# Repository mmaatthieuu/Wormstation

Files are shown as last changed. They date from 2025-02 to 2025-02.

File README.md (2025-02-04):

# Wormstation

A fully open-source, all-in-one platform designed for **ease of use** and **accessibility**, yet offering **powerful, highly automated** solutions for laboratory-grade biological research. Wormstation is **ideal for high-throughput workflows** and **streamlined experimental processes**, particularly in _C. elegans_ studies and other small model organisms.

---

## Repositories

- **Wormstation Controller**  
  [GitHub: wormstation_controller](https://github.com/mmaatthieuu/wormstation_controller)  
  A user-friendly GUI that remotely controls the Wormstation Client software. It manages camera and LED settings, schedules recordings, and facilitates error checks or updates—all from a single interface.

- **Wormstation Client**  
  [GitHub: wormstation_client](https://github.com/mmaatthieuu/wormstation_client)  
  The client software running on each Wormstation device (e.g., Raspberry Pi). It handles local camera captures, LED strobing or continuous illumination, data compression, and robust logging routines.

---

## Hardware Overview

Below is an example Wormstation hardware setup, illustrating the 3D-printed housing, integrated cameras, LED arrays, and other key components:

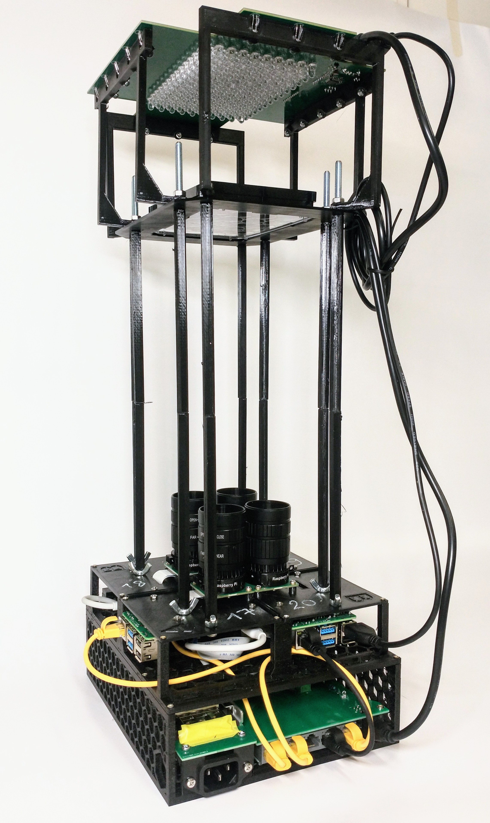
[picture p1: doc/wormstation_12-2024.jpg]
Wormstation Hardware


The complete mechanical and electronic designs (including 3D-printable files and KiCad schematics) are maintained in this repository, making the project fully open and reproducible.

---

## Key Features

- **High-Throughput**  
  Record multiple worms in parallel with automated capture schedules and minimal user intervention.
- **Fully Open-Source**  
  All code, hardware designs, and documentation are freely available for community-driven improvements.
- **Modular & Extensible**  
  Easily replace or upgrade components, adapt the software for new experimental protocols, or integrate additional sensors/actuators.
- **Optogenetics & Advanced Illumination**  
  Precisely control IR, blue, and orange LEDs for non-disruptive observation or targeted neural stimulation.
- **Comprehensive Logging**  
  Both the controller and the client track system status, events, and errors, aiding reproducibility and troubleshooting.

---

## Getting Started

1. **Hardware Assembly**  
   - Print the parts (`3D_print/` directory) and assemble according to the provided instructions.
   - Populate the PCB using KiCad files and a bill of materials found in the `electronics/` directory.
   - Mount the cameras, LED rings, or other illumination modules as described in the hardware guides.

2. **Software Installation**  
   - Set up the [Wormstation Client](https://github.com/mmaatthieuu/wormstation_client) on each device (e.g., Raspberry Pi).
   - Use the [Wormstation Controller](https://github.com/mmaatthieuu/wormstation_controller) GUI on your PC for centralized management.

3. **Configuration**  
   - Provide network addresses or hostnames in a `hosts.txt` file so the controller can detect each Wormstation on the LAN or VPN.
   - Customize recording schedules, LED parameters, and log verbosity per your research needs.

4. **Run Experiments**  
   - Start the controller application, select the devices, and define the experimental parameters.
   - Monitor live frames or single-shot previews to check focus/illumination.
   - Retrieve data automatically from each device or store on a NAS for uninterrupted long-term runs.

---

## Contributing

We welcome feedback, bug reports, and pull requests from the community. Please see the individual repositories for guidelines or open a GitHub Issue if you encounter any problems.

---

## License

This project is made available under the [MIT License](LICENSE). We encourage the community to adapt and expand Wormstation for diverse research applications.

---

## Contact

For questions, collaborations, or to share results:

- **Primary Maintainer**: [@mmaatthieuu](https://github.com/mmaatthieuu)  
- **Email**: [\<insert email\>](mailto:someone@example.com)

We look forward to hearing how Wormstation can accelerate your research!

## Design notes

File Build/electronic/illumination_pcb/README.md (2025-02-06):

# PCB_FT232H

Inspired from https://github.com/MaLoSW/PCB_FT232H

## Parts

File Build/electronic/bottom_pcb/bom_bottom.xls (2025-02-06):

Comment | Designator | Footprint |  | JLCPCB Part #
2 | J9 | PinHeader_1x02_P2.54mm_Vertical | Conn_01x02_Socket | C400349
3 | J8,J7,J6,J3,J2 | TerminalBlock_Phoenix_MKDS-1,5-2-5.08_1x02_P5.08mm_Horizontal | Rpi | C5183929
5 | J4 | DSUB-9_Female_Horizontal_P2.77x2.84mm_EdgePinOffset4.94mm_Housed_MountingHolesOffset7.48mm | DE9_Receptacle_MountingHoles | C3135162

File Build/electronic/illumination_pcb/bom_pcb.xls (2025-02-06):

Comment | Designator | Footprint | JLCPCB Part #
 | C1 | Capacitor_THT:CP_Radial_D10.0mm_P5.00mm | C2891075
D_sub15 | J1 | DSUB-9_Male_Horizontal_P2.77x2.84mm_EdgePinOffset4.94mm_Housed_MountingHolesOffset7.48mm | C591957
 | R1 | R_Axial_DIN0918_L18.0mm_D9.0mm_P22.86mm_Horizontal | C70856
 | J3,J4 | Connector_PinHeader_2.54mm:PinHeader_1x02_P2.54mm_Vertical | C400349
R1_other |  |  | C1364346
 |  |  |  | 1.7515
 |  |  |  | 3.3515

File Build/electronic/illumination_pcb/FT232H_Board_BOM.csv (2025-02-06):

Id | Designator | Footprint | Quantity | Designation | Supplier and ref
1 | H8,H7,H6,H5,H4,H3,H2,H1 | MountingHole_2.2mm_M2_Pad_Via | 8 | MountingHole
2 | C1,C2,C12,C6,C8,C13,C14,C16,C15,C10,C18 | C_0603_1608Metric_Pad1.08x0.95mm_HandSolder | 11 | 0.1uF
3 | C3,C4 | C_0603_1608Metric_Pad1.08x0.95mm_HandSolder | 2 | 27pF
4 | C17 | C_0603_1608Metric_Pad1.08x0.95mm_HandSolder | 1 | 10nF
5 | J3 | PinHeader_1x10_P2.54mm_Vertical | 1 | Conn_01x10
6 | L2,L3,L1 | L_0603_1608Metric_Pad1.05x0.95mm_HandSolder | 3 | 600R@0.5A
7 | R2,R21,R19 | R_0805_2012Metric_Pad1.20x1.40mm_HandSolder | 3 | 10k
8 | R5 | R_0805_2012Metric_Pad1.20x1.40mm_HandSolder | 1 | 12K@1%
9 | R6 | R_0805_2012Metric_Pad1.20x1.40mm_HandSolder | 1 | 2k
10 | U2 | SOT-23-6_Handsoldering | 1 | 93LCxxBxxOT
11 | R3,R4,R1,R23 | R_0805_2012Metric_Pad1.20x1.40mm_HandSolder | 4 | 0R
12 | PWR1,D5 | LED_0805_2012Metric_Pad1.15x1.40mm_HandSolder | 2 | RED
13 | R7,R18 | R_0805_2012Metric_Pad1.20x1.40mm_HandSolder | 2 | 600R
14 | J2 | PinHeader_1x08_P2.54mm_Vertical | 1 | Conn_01x08
15 | R8,R9,R10 | R_0805_2012Metric_Pad1.20x1.40mm_HandSolder | 3 | 10K
16 | Y1 | Crystal_SMD_5032-2Pin_5.0x3.2mm_HandSoldering | 1 | 12MHz@12ppm
17 | F1 | Fuse_0805_2012Metric_Pad1.15x1.40mm_HandSolder | 1 | 0ZCK0010FF2G
18 | J1 | USB_B_OST_USB-B1HSxx_Horizontal | 1 | USB_B
19 | C11,C7 | CP_EIA-1608-10_AVX-L_Pad1.25x1.05mm_HandSolder | 2 | 4.7uF
20 | J4 | PinHeader_2x02_P2.54mm_Vertical | 1 | POWER
21 | R12,R14,R13 | R_0805_2012Metric_Pad1.20x1.40mm_HandSolder | 3 | 1.3k
22 | C24,C23,C22 | C_0603_1608Metric_Pad1.08x0.95mm_HandSolder | 3 | 1nF
23 | D3,D2,D4,D6 | LED_0603_1608Metric_Pad1.05x0.95mm_HandSolder | 4 | GREEN
24 | R22 | R_0805_2012Metric_Pad1.20x1.40mm_HandSolder | 1 | 100
25 | U4,U5,U3 | QFN-40-1EP_5x5mm_P0.4mm_EP3.6x3.6mm_ThermalVias | 3 | LP5860T
26 | R11,R16,R15 | R_0805_2012Metric_Pad1.20x1.40mm_HandSolder | 3 | 4.7kR
27 | C26,C28,C31,C32,C21,C33,C27,C20,C19 | C_0603_1608Metric_Pad1.08x0.95mm_HandSolder | 9 | 1uF
28 | J5 | Molex_Micro-Fit_3.0_43045-0421_2x02-1MP_P3.00mm_Horizontal | 1 | Molex Micro-Fit
29 | R17,R20 | R_0805_2012Metric_Pad1.20x1.40mm_HandSolder | 2 | 480R
30 | D1 | LED_0603_1608Metric_Pad1.05x0.95mm_HandSolder | 1 | YELLOW
31 | D7 | LED_1206_3216Metric_Pad1.42x1.75mm_HandSolder | 1 | BLUE
32 | SW1 | SW_Push_2P2T_Toggle_CK_PVA2xxH3xxxxxxV2 | 1 | RESET
33 | C30 | CP_Radial_D10.0mm_P5.00mm | 1 | 1000uF
34 | C5,C9 | CP_EIA-1608-08_AVX-J_Pad1.25x1.05mm_HandSolder | 2 | 4.7uF
35 | U1 | LQFP-48_7x7mm_P0.5mm | 1 | FT232H
36 | TVS2,TVS1 | D_0603_1608Metric_Pad1.05x0.95mm_HandSolder | 2 | PGB1010603
37 | DO53,DO87,DO104,DO86,DO3,DO18,DO47,DO60,DO32,DO70,DO56,DO83,DO35,DO111,DO82,DO19,DO69,DO25,DO17,DO105,DO94,DO67,DO103,DO8,DO88,DO54,DO36,DO2,DO1,DO50,DO95,DO49,DO6,DO110,DO55,DO52,DO89,DO37,DO77,DO115,DO63,DO15,DO68,DO45,DO109,DO9,DO75,DO41,DO34,DO26,DO99,DO116,DO80,DO65,DO10,DO72,DO23,DO16,DO31,DO112,DO4,DO73,DO108,DO43,DO81,DO85,DO44,DO117,DO13,DO7,DO14,DO79,DO38,DO74,DO61,DO92,DO28,DO40,DO66,DO5,DO71,DO51,DO96,DO39,DO22,DO62,DO76,DO11,DO46,DO107,DO100,DO91,DO90,DO27,DO24,DO98,DO21,DO93,DO113,DO48,DO29,DO97,DO33,DO57,DO59,DO106,DO101,DO20,DO78,DO114,DO84,DO64,DO42,DO102,DO58,DO12,DO30 | LED_D5.0mm | 117 | LED_Opto_590
38 | DB103,DB14,DB92,DB133,DB38,DB41,DB62,DB25,DB125,DB70,DB108,DB137,DB83,DB23,DB60,DB1,DB121,DB10,DB24,DB6,DB78,DB99,DB2,DB31,DB16,DB89,DB20,DB66,DB77,DB76,DB132,DB127,DB105,DB13,DB46,DB93,DB85,DB64,DB27,DB128,DB57,DB17,DB67,DB40,DB12,DB110,DB140,DB86,DB54,DB9,DB129,DB95,DB75,DB130,DB113,DB104,DB48,DB19,DB126,DB69,DB61,DB109,DB15,DB7,DB11,DB18,DB65,DB74,DB51,DB34,DB114,DB101,DB73,DB134,DB120,DB47,DB63,DB80,DB36,DB115,DB72,DB4,DB52,DB111,DB82,DB58,DB44,DB136,DB139,DB33,DB123,DB100,DB22,DB131,DB119,DB53,DB3,DB5,DB91,DB90,DB97,DB122,DB117,DB79,DB43,DB107,DB49,DB37,DB84,DB68,DB32,DB118,DB98,DB116,DB87,DB106,DB42,DB8,DB30,DB94,DB28,DB35,DB56,DB39,DB138,DB96,DB112,DB26,DB71,DB59,DB102,DB81,DB29,DB88,DB21,DB50,DB124,DB55,DB45,DB135 | LED_D5.0mm | 140 | LED_Blue_470
39 | DIR16,DIR7,DIR1,DIR4,DIR5,DIR11,DIR13,DIR12,DIR10,DIR14,DIR9,DIR8,DIR3,DIR6,DIR15,DIR2 | LED_D5.0mm | 16 | LED_IR_850
40 | Q1,Q2 | SOT-23 | 2 | NPN
41 | C25 | CP_EIA-1608-10_AVX-L_Pad1.25x1.05mm_HandSolder | 1 | 10uF

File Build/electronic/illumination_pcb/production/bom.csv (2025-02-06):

Designator | Footprint | Quantity | Value | LCSC Part #
C1, C10, C12, C13, C14, C15, C16, C18, C2, C6, C8 | 0402 | 11 | 0.1uF | C2655418
C11, C5, C7, C9 | 0603 | 4 | 4.7uF | C5596636
C17 | 0603 | 1 | 10nF | C43253
C19, C20, C21, C26, C27, C28, C31, C32, C33 | 0603 | 9 | 1uF | C76619
C22, C23, C24 | 0402 | 3 | 1nF | C147546
C25 | 1210 | 1 | 10uF | C597571
C3, C4 | 0402 | 2 | 16pF | C513591
C30 | CP_Radial_D8.0mm_P3.50mm | 1 | 1000uF | C840077
D1, D2, D3 | 0603 | 3 | YELLOW | C189306
D4, D6 | 0603 | 2 | GREEN | C7496818
D5, PWR1 | 0805 | 2 | RED | C7496834
D7 | 1206 | 1 | BLUE | C965858
DB1, DB10, DB100, DB101, DB102, DB103, DB104, DB105, DB106, DB107, DB108, DB109, DB11, DB110, DB111, DB112, DB113, DB114, DB115, DB116, DB117, DB118, DB119, DB12, DB120, DB121, DB122, DB123, DB124, DB125, DB126, DB127, DB128, DB129, DB13, DB130, DB131, DB132, DB133, DB134, DB135, DB136, DB137, DB138, DB139, DB14, DB140, DB15, DB16, DB17, DB18, DB19, DB2, DB20, DB21, DB22, DB23, DB24, DB25, DB26, DB27, DB28, DB29, DB3, DB30, DB31, DB32, DB33, DB34, DB35, DB36, DB37, DB38, DB39, DB4, DB40, DB41, DB42, DB43, DB44, DB45, DB46, DB47, DB48, DB49, DB5, DB50, DB51, DB52, DB53, DB54, DB55, DB56, DB57, DB58, DB59, DB6, DB60, DB61, DB62, DB63, DB64, DB65, DB66, DB67, DB68, DB69, DB7, DB70, DB71, DB72, DB73, DB74, DB75, DB76, DB77, DB78, DB79, DB8, DB80, DB81, DB82, DB83, DB84, DB85, DB86, DB87, DB88, DB89, DB9, DB90, DB91, DB92, DB93, DB94, DB95, DB96, DB97, DB98, DB99 | LED_D5.0mm | 140 | LED_Blue_470
DIR1, DIR10, DIR11, DIR12, DIR13, DIR14, DIR15, DIR16, DIR2, DIR3, DIR4, DIR5, DIR6, DIR7, DIR8, DIR9 | LED_D5.0mm | 16 | LED_IR_850
DO1, DO10, DO100, DO101, DO102, DO103, DO104, DO105, DO106, DO107, DO108, DO109, DO11, DO110, DO111, DO112, DO113, DO114, DO115, DO116, DO117, DO12, DO13, DO14, DO15, DO16, DO17, DO18, DO19, DO2, DO20, DO21, DO22, DO23, DO24, DO25, DO26, DO27, DO28, DO29, DO3, DO30, DO31, DO32, DO33, DO34, DO35, DO36, DO37, DO38, DO39, DO4, DO40, DO41, DO42, DO43, DO44, DO45, DO46, DO47, DO48, DO49, DO5, DO50, DO51, DO52, DO53, DO54, DO55, DO56, DO57, DO58, DO59, DO6, DO60, DO61, DO62, DO63, DO64, DO65, DO66, DO67, DO68, DO69, DO7, DO70, DO71, DO72, DO73, DO74, DO75, DO76, DO77, DO78, DO79, DO8, DO80, DO81, DO82, DO83, DO84, DO85, DO86, DO87, DO88, DO89, DO9, DO90, DO91, DO92, DO93, DO94, DO95, DO96, DO97, DO98, DO99 | LED_D5.0mm | 117 | LED_Opto_590
F1 | 0805 | 1 | 0ZCK0010FF2G | C516070
H1, H2, H3, H4, H5, H6, H7, H8 | MountingHole_2.2mm_M2_Pad_Via | 8 | MountingHole
J1 | USB_B_OST_USB-B1HSxx_Horizontal | 1 | USB_B | C464566
J2 | PinHeader_1x08_P2.54mm_Vertical | 1 | Conn_01x08 | C6332201
J3 | PinHeader_1x10_P2.54mm_Vertical | 1 | Conn_01x10 | C5383117
J4 | PinHeader_2x02_P2.54mm_Vertical | 1 | POWER | C5383103
J5 | Molex_Micro-Fit_3.0_43045-0400_2x02_P3.00mm_Horizontal | 1 | Molex Micro-Fit | C122413
L1, L2, L3 | L_Murata_LQH2MCNxxxx02_2.0x1.6mm | 3 | 600R@0.5A | C917337
Q1, Q2 | SOT-23 | 2 | NPN | C18221467
R1, R23, R3, R4 | 1206 | 4 | 0R | C2074152
R10, R19, R2, R21, R8, R9 | 0805 | 6 | 10k | C163957
R11, R15, R16 | 0805 | 3 | 4.7kR | C192064
R12, R13, R14 | 0603 | 3 | 1.3k | C334843
R17, R20 | 0805 | 2 | 480R | C144560
R18, R7 | 0805 | 2 | 600R | C706363
R22 | 0603 | 1 | 100 | C844726
R5 | 0805 | 1 | 12K@1% | C515719
R6 | 0805 | 1 | 2k | C2934151
SW1 | SW_Push_2P2T_Toggle_CK_PVA2xxH3xxxxxxV2 | 1 | RESET | C528785
TVS1, TVS2 | 0603 | 2 | PGB1010603 | C10677
U1 | LQFP-48_7x7mm_P0.5mm | 1 | FT232H | C51997
U2 | SOT-23-6_Handsoldering | 1 | 93LCxxBxxOT | C190271
U3, U4, U5 | QFN-40-1EP_5x5mm_P0.4mm_EP3.6x3.6mm | 3 | LP5860T | C22427238
Y1 | Crystal_SMD_3225-4Pin_3.2x2.5mm_HandSoldering | 1 | 12MHz@12ppm | C668846

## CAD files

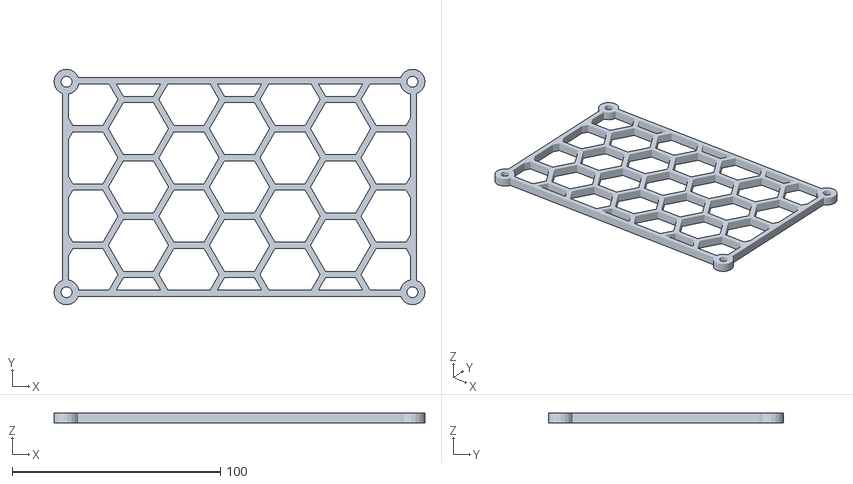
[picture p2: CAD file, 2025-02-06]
Build/3D_print/STL files/led_solder_holder.stl
178.0 x 113.0 x 5.00

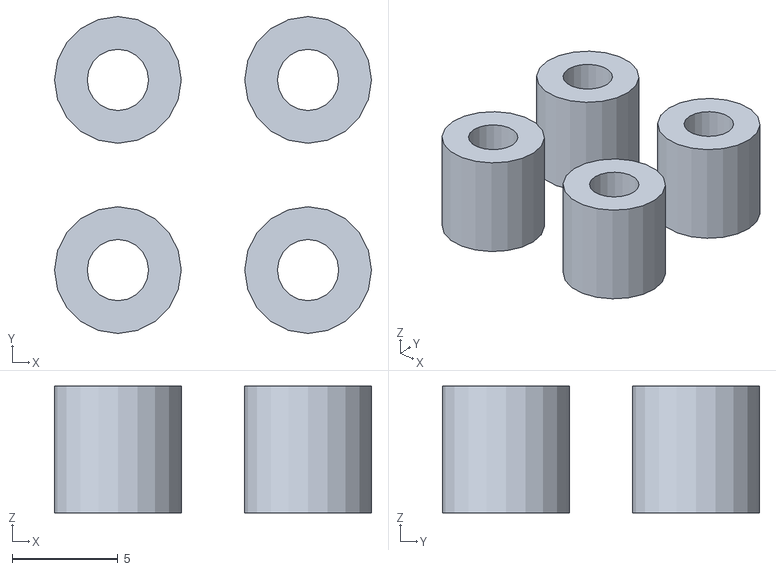
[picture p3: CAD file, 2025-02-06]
Build/3D_print/STL files/spacers.stl
15.0 x 15.0 x 6.00

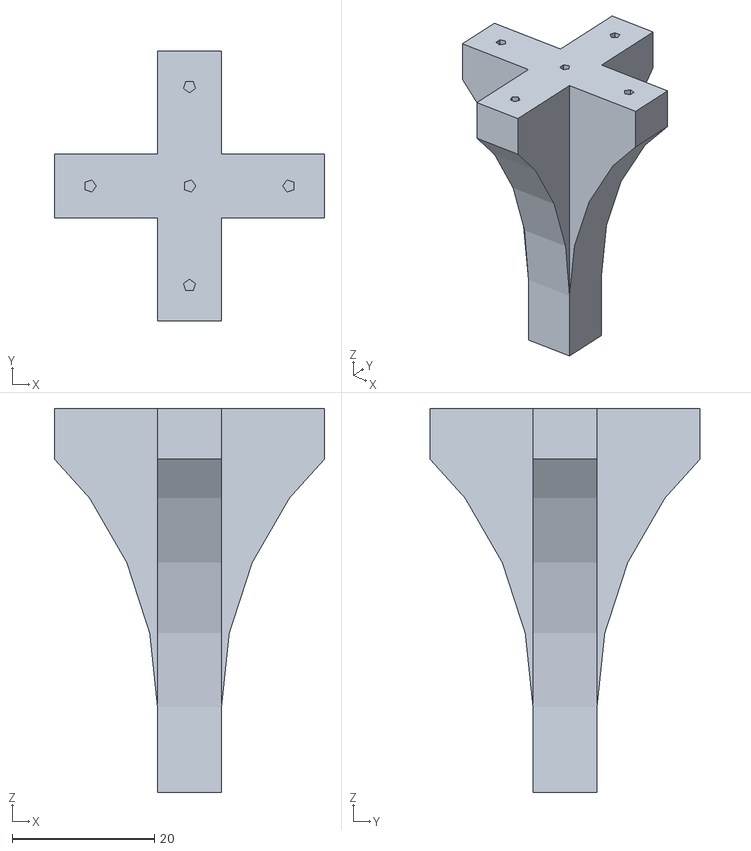
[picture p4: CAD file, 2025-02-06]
Build/3D_print/STL files/central_pillar.stl
38.0 x 38.0 x 54.0

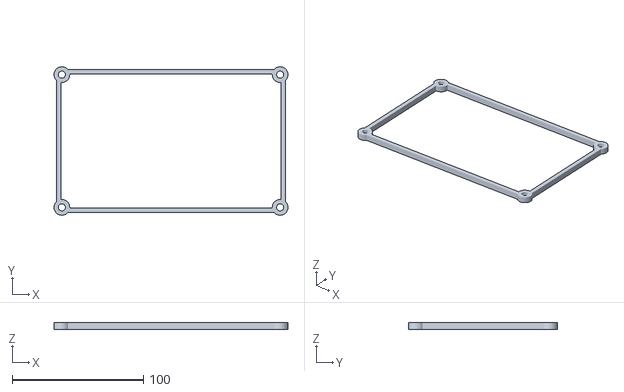
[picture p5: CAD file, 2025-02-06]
Build/3D_print/STL files/led_solder_mold_rect.stl
178.0 x 113.0 x 5.00

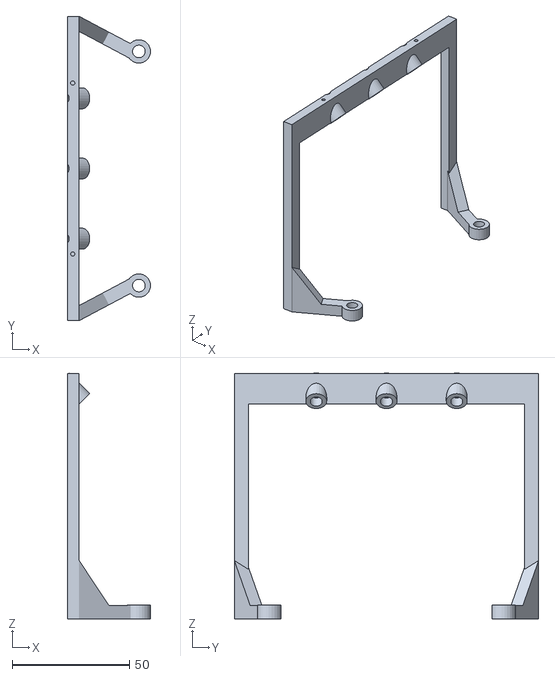
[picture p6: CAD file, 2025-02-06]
Build/3D_print/STL files/multi_led_3.stl
35.5 x 130.0 x 105.1

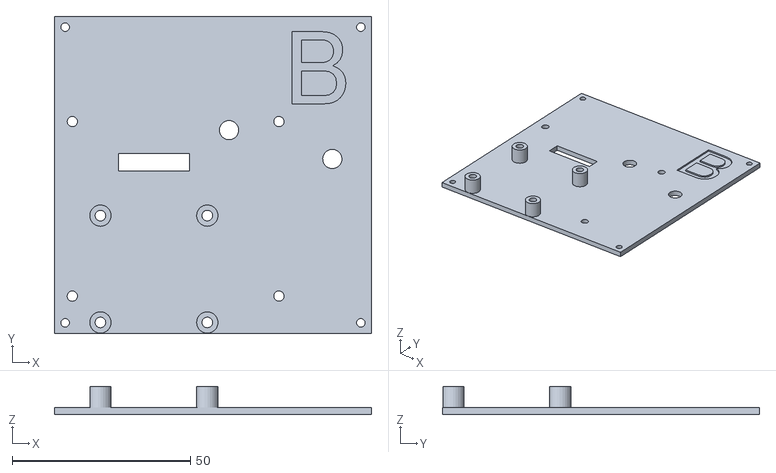
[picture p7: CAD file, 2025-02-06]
Build/3D_print/STL files/Camera_plate_B.stl
89.0 x 89.0 x 8.00

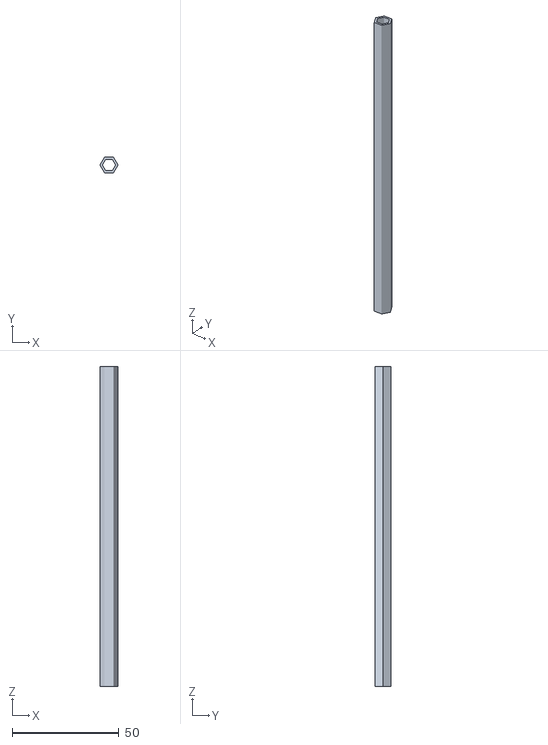
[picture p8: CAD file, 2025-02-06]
Build/3D_print/STL files/leg150.stl
8.50 x 7.36 x 150.0

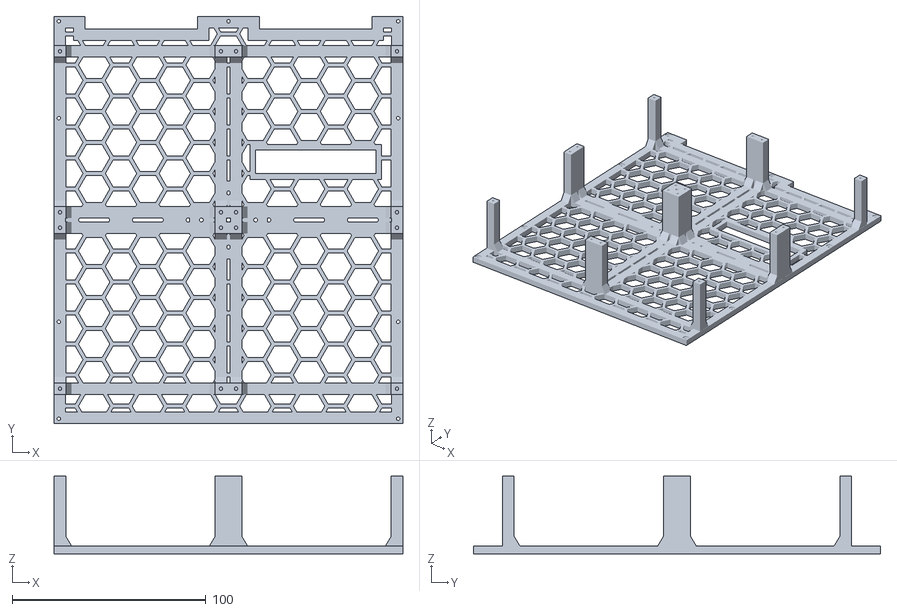
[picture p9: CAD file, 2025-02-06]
Build/3D_print/STL files/middle.stl
180.0 x 210.0 x 40.0

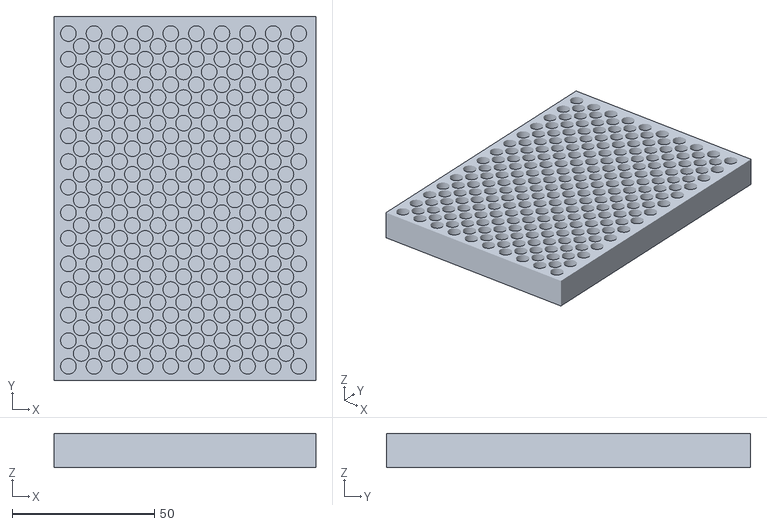
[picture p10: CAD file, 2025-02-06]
Build/3D_print/STL files/led_solder_mold.stl
92.0 x 128.0 x 12.0

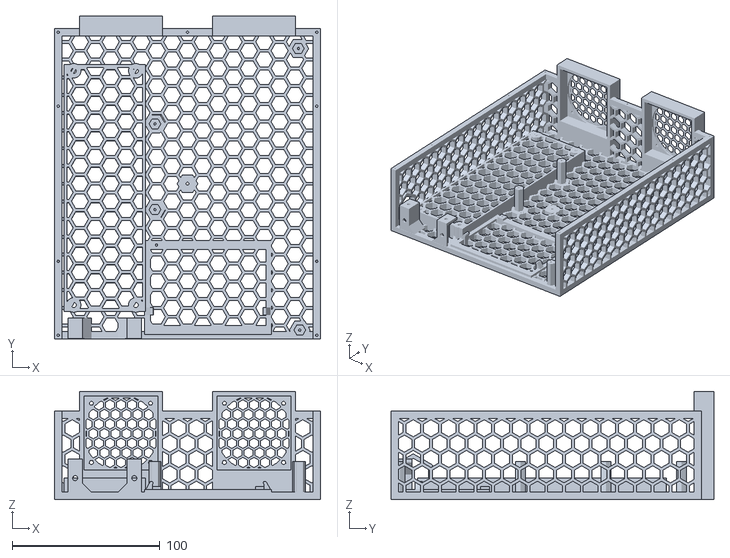
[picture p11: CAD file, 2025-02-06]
Build/3D_print/STL files/bottom.stl
180.0 x 218.6 x 73.2

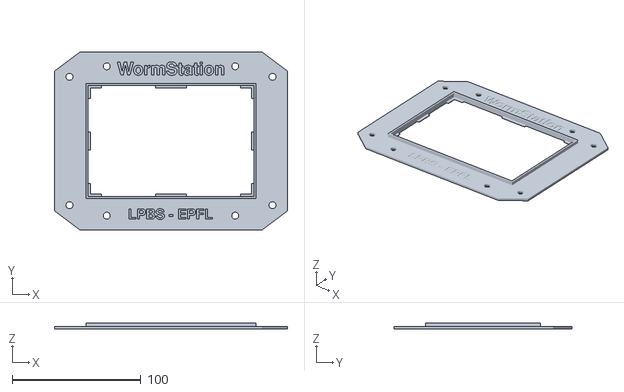
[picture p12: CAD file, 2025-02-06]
Build/3D_print/STL files/microwell_holder.stl
181.1 x 138.6 x 5.00

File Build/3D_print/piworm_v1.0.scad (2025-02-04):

/*
 * Wormstation
 * by Matthieu Schmidt - https://github.com/mmaatthieuu/Wormstation
 * created 2021-03-15
 * updated 2025-01-09
 * version v1.0
 *
 * Changelog
 * --------------
 * v1.0:
 *      - Massive clean
 *      - Improved customizer
 * v0.6.2:
 *      - New basement floor for new PCB
 *      - New basement
 *      - Remove side wall on cam plate
 *      - Remove old modules
 *      - Multi_LED_bar_v3 (more space between legs for N=3)
 * v0.6.1:
 *      - remove unused modules
 *      - wheels, breadboard, windshield
 * v0.6:
 *      - add screw holes in Led bars
 *      - add PCB cover
 *      - one single big foot
 *      - add chemotaxis mode
 *      - remove unused parts in the code
 * --------------
 *
 * This work is licensed under the MIT License.
 */


 // Parameter Section //
//-------------------//

/* [Global display settings] */


// Enable Draft Mode to ignore shape details and speed up rendering. It also shows non-pritable parts as lenses or perti dishes.
DRAFT_MODE = true;


// Choose between a setup for microwell plates or 5cm petri plates
SETUP_VERSION = "Microwell"; // [Microwell, Petri]

// Render all parts
SHOW_ALL = false;

// Show light emitted by the LEDs
Show_light_rays = false;

/* [Main parts display settings] */

Multi_LED_bar = false;
Multi_LED_bar_size= 5; // [3,4,5]

Multiwell_holder = false;
Large_plate_holder = false;
Leg=false;


Camera_plate_A = false;
Camera_plate_B = false;

Central_pillar=false;
Basement=false;
Basement_floor=false;



/* [Secondary parts display settings] */

Petri_adapter = false;
Spacers = false;

Filter_adapter=false;
Filter_adapter_HQ_long=false;
Filter_adapter_HQ_short=false;

Led_solder_mold=false;







/* [Custom Settings] */





//____________ VARIABLES ______________

tolerance = 0.2;

width = 2;
width_cam_plate = 2; //same as width

leg_space = 50.0;


LED_insert_width = 9;


LED_angle = 137;
LED_height = 250;
LED_shift = 90;
LED_viewing_angle = 20;



petri_filler_thickness = 12;

Leg_length=150; // [80:220]


middle_floor_thickness = 4;

pillar_position_1 = [-30,3.65,0];
//pillar_position_2 = 


 // Import Section //
//-------------------//


module mount(){
    
    import("lib/lens_mount.stl");
    
}
// EXTERNAL FILES

use <lib/threads.scad> 
use <lib/basic_shapes.scad>
use <lib/hex-grid.scad>




//____________ PHYSICAL PARAMETERS ______________


large_d = 88.1+tolerance;   // Main petri dish
small_d = 36+tolerance;   // Small petri dishes

large_d_in = 86.8-tolerance;  // Inside diameter main petri dish

external_size = 89;
o = external_size*0.5*0.8;


camera_hole = 9.2+tolerance; // 8mm square
camera_x = 30.0;
camera_screw_centre_offset = 0.0;
camera_screw_x = 12.5;
camera_screw_y = 21.0; // 21mm screw spacing
camera_screw_r = 1.5; // m2
camera_cable_y = 20.0;
camera_cable_h = 1.0;



//____________ GLOBAL VALUES ______________


R_ext = large_d/2;
r = small_d/2+0.1;

R_in = large_d_in/2;


imbrications_size = 1;

space_between_plates = 1.8;

//wall = 2;


sep = 10;

feet_height=40;
feet_width = 6;
feet_center_pos = external_size/2-feet_width/2;

fcp = feet_center_pos;





L=R_in-r;
alpha=(asin(r/L)-45)*2;



//////////////////////////////////////////

if(SHOW_ALL){
    DRAFT_MODE = true;
    show_all();
}
module show_all(){
    

   
  if(SETUP_VERSION == "Petri"){
      translate([0,0,135])large_plate_holder_v2();
      
    translate([0,31.5,0])multi_LED_bar_v3(4);
    mirror([0,1,0])translate([0,31.5,0])multi_LED_bar_v3(4);
    translate([-31.5,0,0])rotate([0,0,90])multi_LED_bar_v3(4);
      
      
  }
  else{
      translate([0,0,135])multiwell_holder();
      
      translate([0,31.5,0])multi_LED_bar_v3(5);
      mirror([0,1,0])translate([0,31.5,0])multi_LED_bar_v3(5);
      translate([-31.5,0,0])rotate([0,0,90])multi_LED_bar_v3(3);
  }
    
  camera_plate();
  rotate([0,0,90]){
    translate([0,0,-90])basement_v2();
    translate([0,0,-110])basement_floor_v2();
  }

    

    
}





module LED_bar_foot(h, shift){
    translate([0,shift,h])mCube(6-tolerance/2,5,95);
    
    // Corners for robustness
    translate([-3,shift-16,h+5])prism(6,15,20);
    
    translate([0,shift-19+12,h])mCube(6,15,6-tolerance/2);
    
    difference(){
        union(){
            translate([0,shift-19-0,h])mCube(6-tolerance*1.5,20,6-tolerance*1.5);
            translate([0,shift-19-2*4-1,h])rotate([0,0,0])cylinder(h=6-tolerance/2,d=10);
        }
        translate([0,shift-19-2*4-1,h])rotate([0,0,0])cylinder(h=200,d=5.4);
    }
}

module LED_bar_foot_rotation(h, shift){

    leg_offset = 12;
    
    translate([leg_offset,shift,h])mCube(6-tolerance/2,5,95);
    
    // Corners for robustness
    translate([5.93,2.95,0])translate([-3,shift-16,h+5])rotate([0,0,-28])prism(5.7,15,20);
    
    //translate([0,shift-19+12,h])mCube(6,15,6-tolerance/2);
    
    difference(){
        union(){
            translate([5.443,shift-19+4.6,h])rotate([0,0,-28])mCube(6-tolerance*1.5,30,6-tolerance*1.5);
            translate([0,shift-19-2*4-1,h])rotate([0,0,0])cylinder(h=6-tolerance/2,d=10);
        }
        translate([0,shift-19-2*4-1,h])rotate([0,0,0])cylinder(h=200,d=5.4);
    }
    
}

module crop_LED_bar(L,width){
    difference(){
        mCube(L,width,13);
        for(m=[0,1]){
            mirror([m,0,0])translate([leg_space,-4,13])rotate([65,0,0])cube(10,10,10);
        }
    }
}

module multi_LED_bar_v3(N, rotate_feet=false){
    
    //bool_64 = -(N-4)*0.5; // 0 si N==6, 1 si N==4
    bool_64 = 0;
    
    //shift = 85+ bool_64*(127.2-85.1)/2;
    //echo(str(shift));
    shift = 74.5+1;
    //x_shift = -bool_64 * 1;
    x_shift = 0;
    width = 5;
    h=135+3+tolerance/2;
    y_space = leg_space;
    
    //angle_0 = 142 - (bool_64*4.5);
    angle_0 = 143;
    
    echo(N);
    echo(angle_0);
    
    pcb_holes_space = 123;
    
    $fn=25;
    
    difference(){
        union(){
            // Main bar
            if(N==5){
                translate([x_shift,shift,230])crop_LED_bar(130,width);
            }
            else{
                translate([x_shift,shift,230])mCube(130,width,13);
            }
            
            
            //LED tubes
            translate([x_shift,shift+5,240])rotate([0,-angle_0+8,90])LED_bar(N);
            
            
            for(m=[0,1]){
                if(N==3){
                    mirror([m,0,0])translate([y_space,-0,0])LED_bar_foot_rotation(h, shift);
                }
                else{
                    mirror([m,0,0])translate([y_space,-0,0])LED_bar_foot(h, shift);
                }
            }
           
            
        }
        
        union(){
        //translate([x_shift,shift,260])rotate([0,-angle_0,90])LED_bar_negative(N);
        translate([x_shift,shift+5,240])rotate([0,-angle_0+8,90])LED_bar_negative(N);
        //translate([x_shift,shift+5,220])rotate([0,-angle_0+13,90])LED_bar_negative(N);
        translate([x_shift,shift+width+width/2,210])mCube(300,width*2,55);
        
        // PCB screw hole
         if(N==3){
             pcb_holes_space = 73;   // if N==3
             translate([pcb_holes_space/2,-31.5+150.25-43,h+95-3])cylinder(h=13, d=1.85);
             mirror([1,0,0])translate([pcb_holes_space/2,-31.5+150.25-43,h+95-3])cylinder(h=13, d=1.8);
         }
         else{  // N==4 or 5
            pcb_holes_space = 123;
            translate([pcb_holes_space/2,-31.5+150.25-43,h+95-3])cylinder(h=13, d=1.85);
            mirror([1,0,0])translate([pcb_holes_space/2,-31.5+150.25-43,h+95-3])cylinder(h=13, d=1.8);
          }
        
        }
    
             
    }
    
    
}
if(Multi_LED_bar){
    translate([0,0,85])
    //for(i=[0,1]){
    for(i=[0]){
mirror([i,0,0])rotate([0,0,90])translate([0,31.5,-86])multi_LED_bar_v3(Multi_LED_bar_size);
    }
}
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

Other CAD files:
Build/3D_print/STL files/Camera_plate_A.stl
Build/3D_print/STL files/multi_led_5.stl

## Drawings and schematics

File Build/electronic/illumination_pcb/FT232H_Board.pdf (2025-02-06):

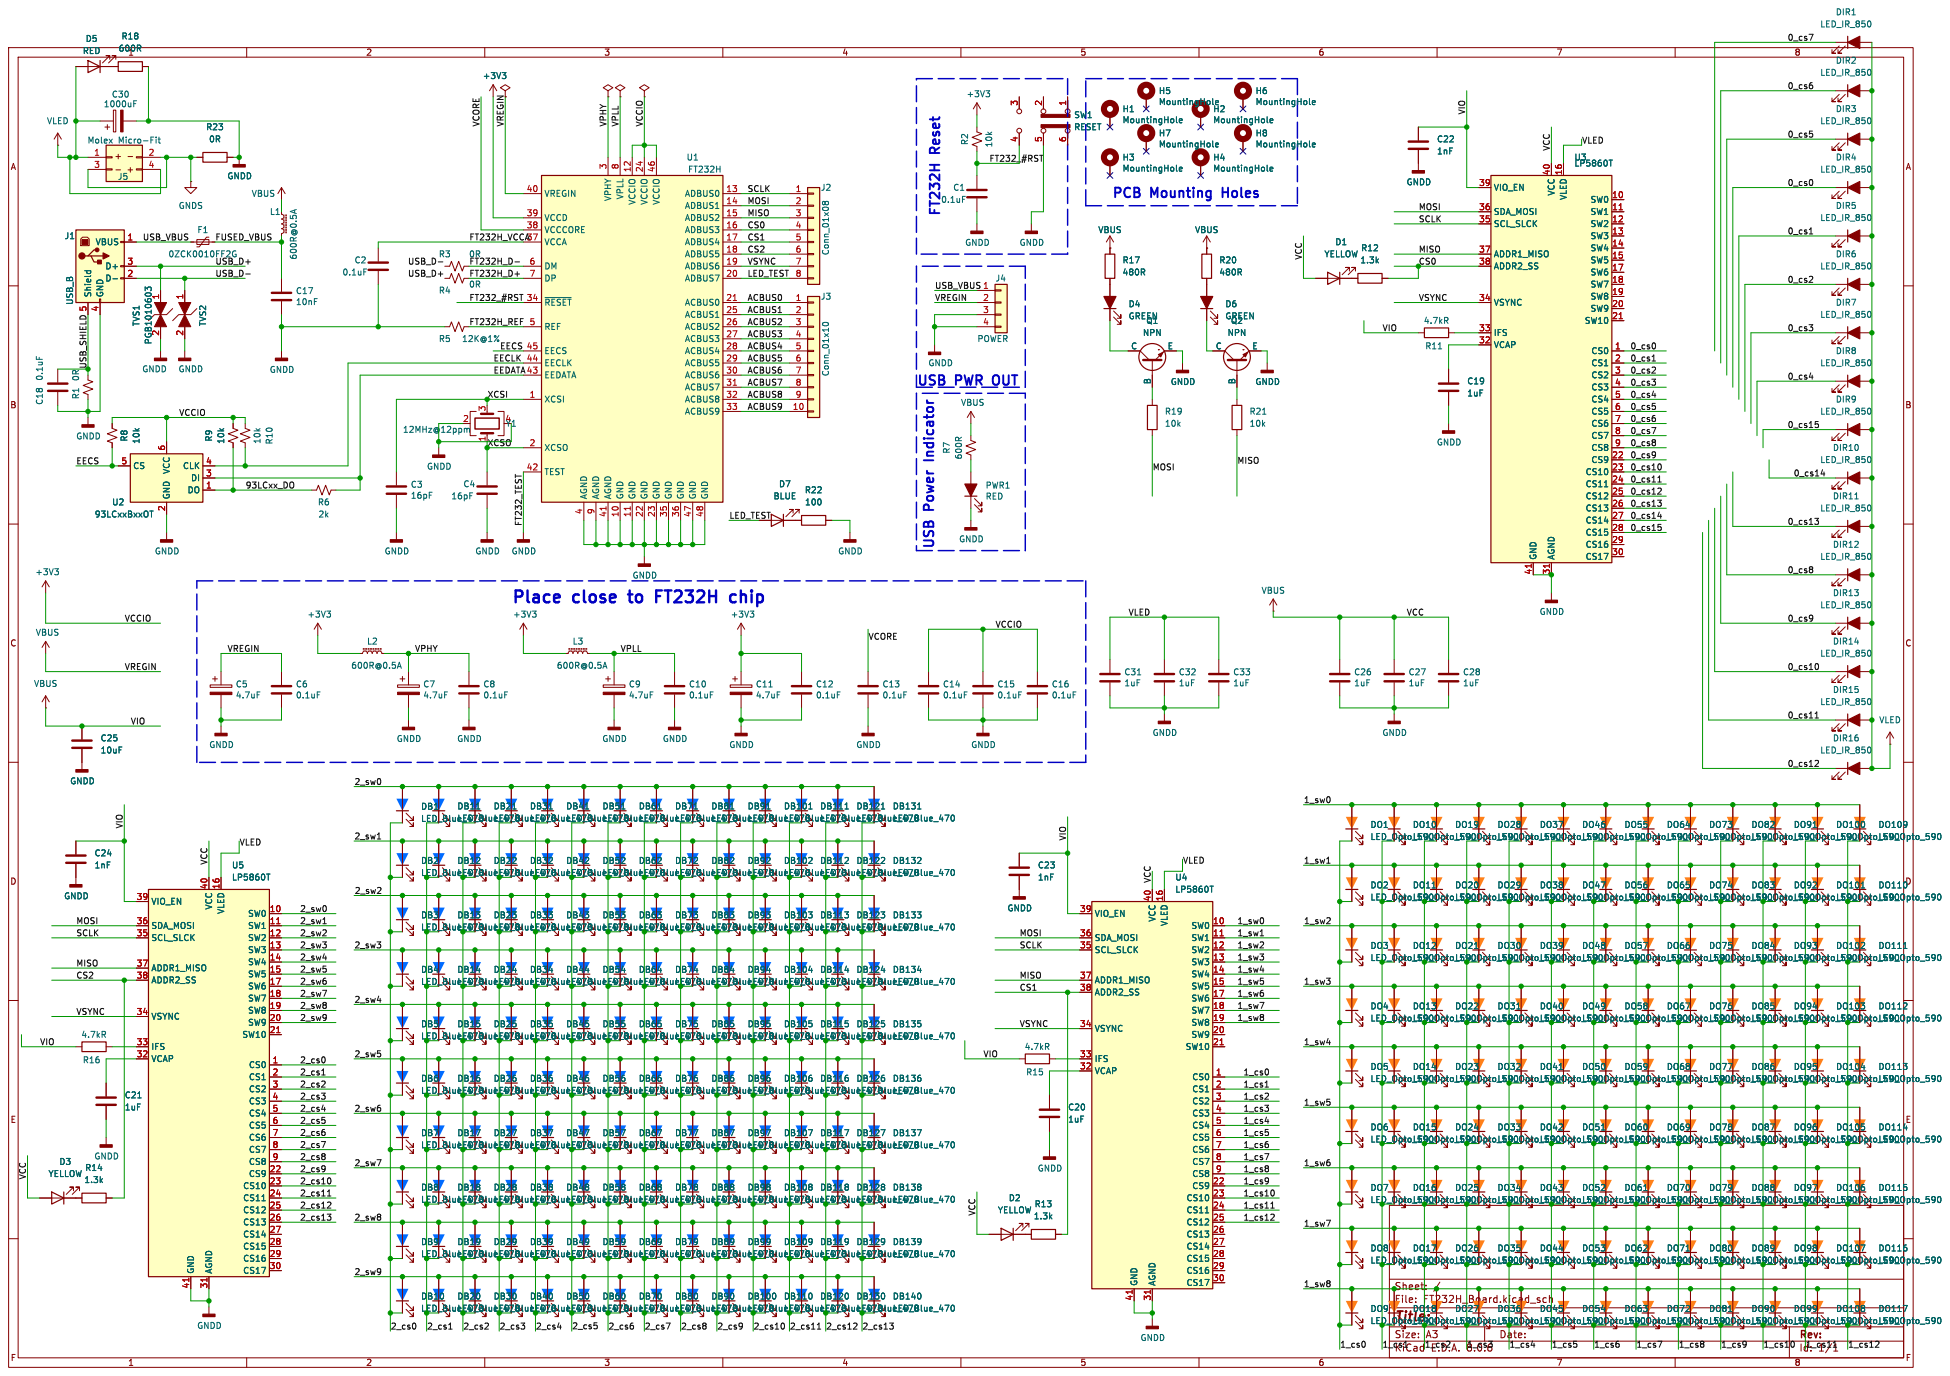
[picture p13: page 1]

MISO MOSI SCLK VPHY
SCLK VPLL

4 VREGIN 40 AGND 41 TEST 42 EEDATA 43 EECLK 44 EECS 45 VCCIO 46 GND 47 GND 48 REF 5 DM 6 DP 7 VPLL

3 ACBUS6 30 ACBUS7 31 ACBUS8 32 ACBUS9 33 ~{RESET} 34 GND 35 GND 36 VCCA 37 VCCCORE 38 VCCD 39 AGND

2 DI 3 CLK 4 CS 5 VCC

Place close to FT232H chip

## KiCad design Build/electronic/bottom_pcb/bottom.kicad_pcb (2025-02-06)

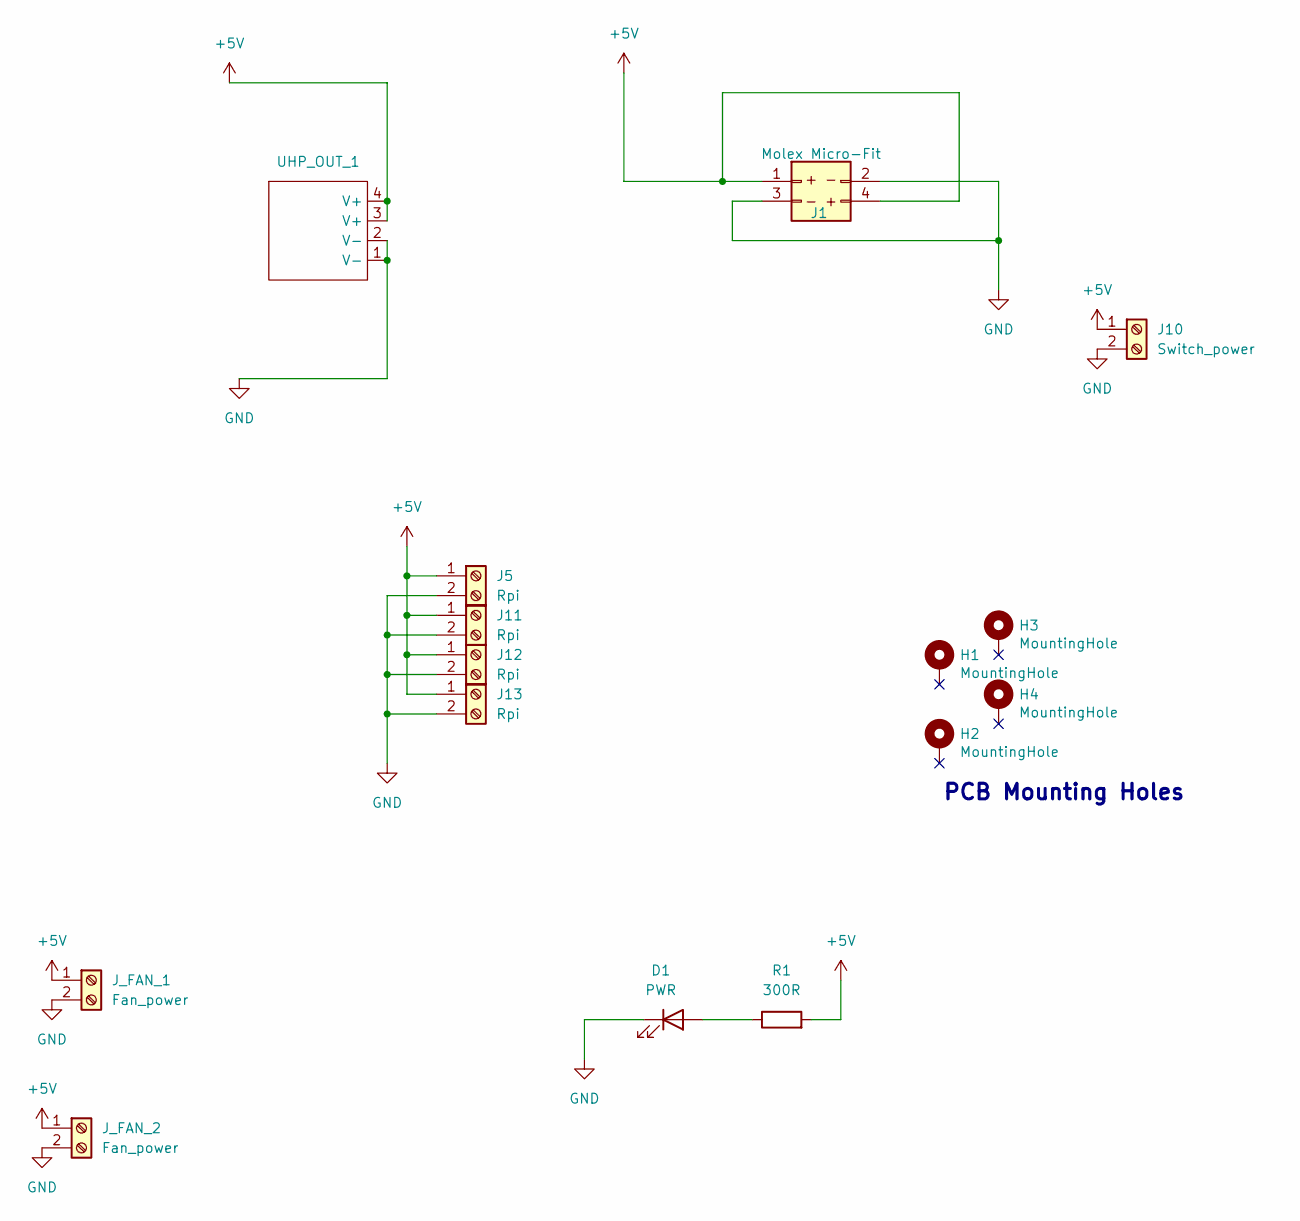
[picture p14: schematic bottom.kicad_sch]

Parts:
D1: PWR; LED_D3.0mm
H1, H2, H3, H4: MountingHole; MountingHole_2.2mm_M2_Pad_Via
J1: Molex Micro-Fit; Molex_Micro-Fit_3.0_43045-0400_2x02_P3.00mm_Horizontal; LCSC C122413
J5, J11, J12, J13: Rpi; TerminalBlock_Phoenix_MKDS-1,5-2-5.08_1x02_P5.08mm_Horizont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
J10: Switch_power; TerminalBlock_Phoenix_MKDS-1,5-2-5.08_1x02_P5.08mm_Horizont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
J_FAN_1, J_FAN_2: Fan_power; TerminalBlock_Phoenix_MKDS-1,5-2-5.08_1x02_P5.08mm_Horizont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
R1: 300R; R_Axial_DIN0207_L6.3mm_D2.5mm_P15.24mm_Horizontal
UHP_OUT_1: UHP-200A-5_output

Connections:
+5V: J1.1 (5V), J1.4, J5.1, J10.1, J11.1, J12.1, J13.1, J_FAN_1.1, J_FAN_2.1, R1.2, UHP_OUT_1.3 (V+), UHP_OUT_1.4 (V+)
GND: D1.1 (K), J1.2 (GND), J1.3 (GND), J5.2, J10.2, J11.2, J12.2, J13.2, J_FAN_1.2, J_FAN_2.2, UHP_OUT_1.1 (V-), UHP_OUT_1.2 (V-)
unnamed: D1.2 (A), R1.1

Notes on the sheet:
PCB Mounting Holes

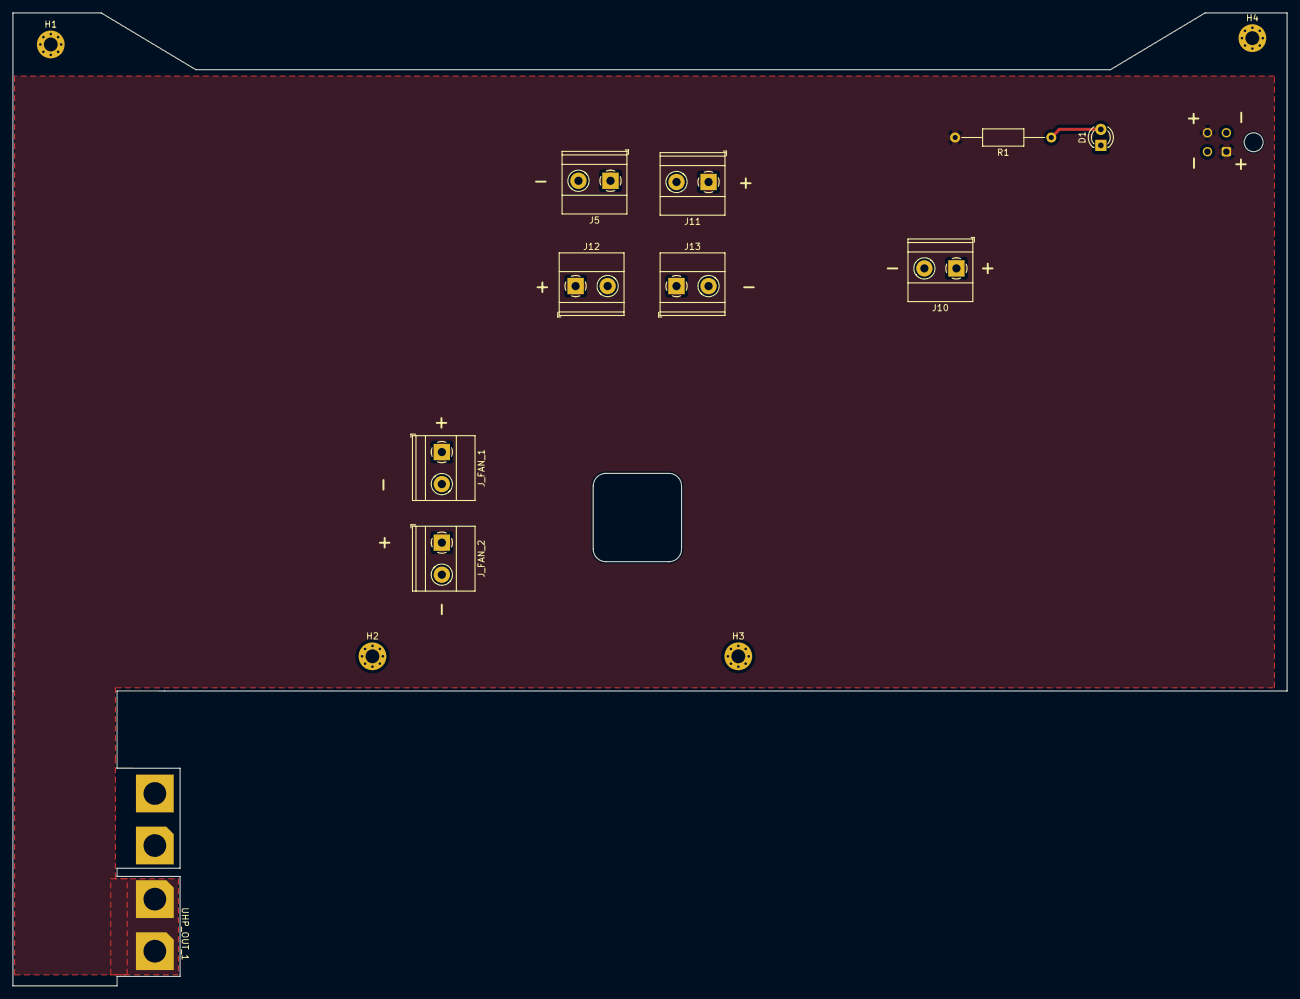
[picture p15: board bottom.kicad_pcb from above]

Board: 2 copper layers, 202.0 x 154.2 mm, 15 parts (1 on the bottom side), 3 nets.

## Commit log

2025-02-04 Improve doc and readme
    [piworm_v1.0.scad]
2025-02-06 add kicad and gcode files
    [Camera_plate_A.stl, Camera_plate_B.stl, FT232H_Board.csv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]
2026-09-30 Add costed bill of materials for one V7 unit
    bom.csv lists every part of one WormStation V7 unit with its quantity
    and invoiced price. build_bom.py converts to EUR (ECB rates of
    2026-09-29) and regenerates list_of_material.md plus two LaTeX tables:
    a per-subsystem summary and a full longtable.
    Total: 967.90 EUR per unit, excluding VAT and shipping.
